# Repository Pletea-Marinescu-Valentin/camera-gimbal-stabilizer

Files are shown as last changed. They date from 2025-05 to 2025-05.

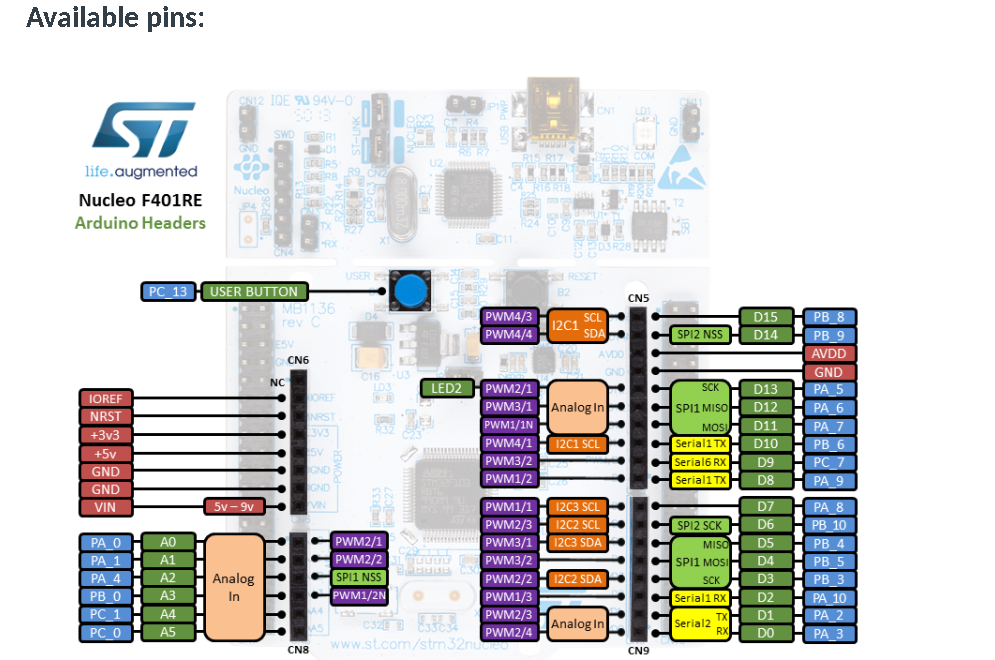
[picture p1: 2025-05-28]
Hardware/stm32-schematics.png

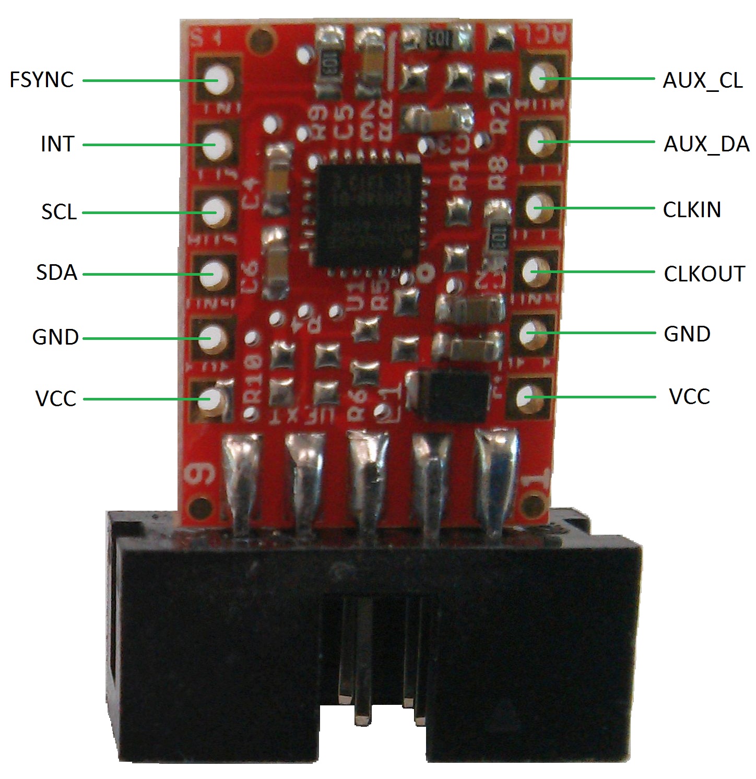
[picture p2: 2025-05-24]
Hardware/named_pins_6050.jpg

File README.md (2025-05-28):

# Camera Gimbal Stabilizer

A two-axis camera stabilization system based on STM32 microcontroller and servo motors.

## Overview

This project implements a two-axis camera gimbal stabilizer using an STM32F401RE microcontroller, MPU6050 inertial sensor, and TowerPro MG996R servo motors with DC-DC power management. The system provides camera stabilization for smooth footage during movement.

### Features

- Two-axis stabilization (pitch and roll)
- Kalman filter-based sensor fusion
- Real-time parameter adjustment via UART
- 3D printed components for mechanical assembly
- Modular design for future expansion
- Support for lightweight cameras and mobile devices
- High-precision servo control with PWM

## Bill of Materials (BOM)

| Component | Quantity | Supplier | Price/Unit | Link | Datasheet |
|---|---|---|---|---|---|
| NUCLEO-F401RE Development Board | 1 | Mouser Electronics | €13.13 | [Mouser](https://ro.mouser.com/ProductDetail/STMicroelectronics/NUCLEO-F401RE?qs=fK8dlpkaUMvGeToFJ6rzdA%3D%3D) | [STM32F401RE Datasheet](https://www.st.com/resource/en/data_brief/nucleo-c031c6.pdf) |
| MPU6050 Gyroscope/Accelerometer Module | 1 | Mouser Electronics | €8.55 | [Mouser](https://ro.mouser.com/ProductDetail/Olimex-Ltd/MOD-MPU6050?qs=SUpef6bDnvVsH%252Bq1tWOBKA%3D%3D) | [MPU6050 Datasheet](https://ro.mouser.com/datasheet/2/306/RM-MPU-60xxA_rev_4-736751.pdf) |
| TowerPro MG996R Servo Motor | 2 | TowerPro | RON 80 | [TowerPro](https://towerpro.com.tw/product/mg996r/) | [MG996R Specifications](https://towerpro.com.tw/product/mg996r/) |
| Module DC-DC Step Down LM2596S | 2 | Optimus Digital | 12.99 RON | [Optimus](https://www.optimusdigital.ro/en/adjustable-step-down-power-supplies/1109-lm2596-dc-dc-step-down-module-5a.html) | [Module Specifications](https://www.optimusdigital.ro/en/adjustable-step-down-power-supplies/1109-lm2596-dc-dc-step-down-module-5a.html) |
| Mini Breadboard | 2 | Mouser Electronics | €2.60 | [Mouser](https://ro.mouser.com/ProductDetail/OSEPP-Electronics/LS-00047?qs=w%2Fv1CP2dgqofvkXBf4F3MQ%3D%3D) | [LS-00047 Datasheet](https://www.osepp.com/accessories/components/162-ls-00047-solder-able-breadboard-mini) |
| Resistors Kit | 1 | Mouser Electronics | €10.84 | [Mouser](https://ro.mouser.com/ProductDetail/SparkFun/COM-10969?qs=WyAARYrbSnYDX0pYE0qQCg%3D%3D) | N/A |
| Plusivo Kit | 1 | Optimus Digital | RON 40 | [Optimus](https://www.optimusdigital.ro/en/kits/12026-plusivo-electronics-starter-kit-0721248990075.html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) | N/A |

## Hardware

### Components

- STM32F401RE Nucleo board
- MPU6050 accelerometer and gyroscope module
- 2× TowerPro MG996R servo motors (high-torque metal gear)
- 2× LM2596S DC-DC step-down modules
- 3D printed mechanical structure
- 12V power supply for servo motors
- USB power for STM32 development board
- Breadboard, connection wires
- Plusivo Kit (sensors, jumpers, accessories)

### Servo Motor Specifications

The TowerPro MG996R servos provide:
- **Operating voltage**: 4.8V - 7.2V (optimized at 6V)
- **Torque**: 9.4 kg⋅cm (4.8V), 11 kg⋅cm (6V)
- **Speed**: 0.20 sec/60° (4.8V), 0.17 sec/60° (6V)
- **Control signal**: PWM (50Hz, 1-2ms pulse width)
- **Weight**: 55g each
- **Metal gear construction** for durability and precision

### Power Management

The LM2596S DC-DC modules provide:
- **Input voltage**: 7V - 35V (12V nominal)
- **Output voltage**: Adjustable 1.25V - 30V (set to 6V)
- **Output current**: Up to 2A continuous
- **Efficiency**: ~85%
- **Protection**: Over-current and thermal protection

### Connections

#### MPU6050 to STM32
- SDA → PB9 (I2C1_SDA)
- SCL → PB8 (I2C1_SCL)
- VCC → 3.3V
- GND → GND

#### UART for debugging:
- TX → PA2 (USART2_TX)
- RX → PA3 (USART2_RX)

#### STM32 to Servo Motors
- PWM1 → PA6 (TIM3_CH1) - X-axis Servo
- PWM2 → PA7 (TIM3_CH2) - Y-axis Servo

#### Power Distribution
- **STM32**: 5V via USB connection
- **MPU6050**: 3.3V from STM32 regulator
- **Servo Motors**: 6V from LM2596S modules
- **DC-DC Input**: 12V external power supply

## Software

The firmware is developed using STM32CubeIDE and leverages the following technologies:

### Core Technologies
- **STM32 HAL** for hardware abstraction
- **I2C communication** for MPU6050 sensor
- **PWM generation** for servo motor control (50Hz, 1-2ms pulse width)
- **Kalman filter** for optimal sensor fusion
- **UART** for debugging and parameter adjustment

### Key Algorithms
- **Sensor Processing**: Raw data acquisition and calibration
- **Kalman Filter**: Advanced sensor fusion for stable angle estimation
- **Servo Control**: Precise PWM-based positioning
- **Real-time Processing**: 100Hz update rate

### Implementation Features
- Custom MPU6050 driver optimized for gimbal applications
- Kalman filter with gyroscope bias estimation
- Servo control with safety limits and smooth movement
- Memory management with custom allocation
- Interrupt-based processing for consistent timing

## Mathematical Model

### Kalman Filter Implementation

The system uses a 2-state Kalman filter for optimal sensor fusion:

**State Vector:**
```
x_k = [θ_k, b_k]ᵀ
```
Where:
- θ_k = Angle estimate at time k
- b_k = Gyroscope bias estimate at time k

**Prediction Step:**
```
θ_{k|k-1} = θ_{k-1|k-1} + (ω_k - b_{k-1|k-1}) × Δt
b_{k|k-1} = b_{k-1|k-1}
```

**Update Step:**
```
θ_{k|k} = θ_{k|k-1} + K_0 × (θ_accel - θ_{k|k-1})
b_{k|k} = b_{k|k-1} + K_1 × (θ_accel - θ_{k|k-1})
```

**Tuning Parameters:**
- Q_angle = 0.001 (process noise for angle)
- Q_bias = 0.003 (process noise for bias)
- R_measure = 0.03 (measurement noise)

## Results

- **Accurate orientation estimation** with significantly reduced noise
- **Stable angle measurement** even under motion or vibration
- **Real-time data reporting** through UART interface
- **Sampling rate** of approximately 100Hz
- **Smooth servo control** with precise positioning
- **Effective power management** through DC-DC conversion

## Future Improvements

- Add a third axis (yaw) for complete 3-axis stabilization
- Implement object tracking capabilities using computer vision
- Integrate wireless control system (Bluetooth/WiFi)
- Add camera trigger synchronization
- Implement auto-calibration routines
- Add mobile app for remote control and parameter adjustment

## Directory Structure

```
├── Core/
│   ├── Src/           # Source code files
│   └── Inc/           # Header files
├── Hardware/          # Electrical schematics and PCB designs
├── Models/            # 3D models for printed components
├── Images/            # Project photos and diagrams
├── Documentation/     # Detailed project documentation
└── Tests/             # Unit tests and validation data
```

## Key Files

- **main.c** - Main application logic and system initialization
- **mpu6050.c/h** - MPU6050 sensor driver and communication
- **kalman.c/h** - Kalman filter implementation
- **servo.c/h** - Servo motor control and PWM management
- **stm32f4xx_hal_msp.c** - Hardware abstraction layer configuration

## Performance Characteristics

### Power Consumption
- **Control circuits**: ~50mA at 3.3V/5V
- **Servo motors**: 10mA idle, up to 1.5A per servo under load
- **Total system**: ~3.5A peak at 12V, ~0.1A idle

### Mechanical Specifications
- **Payload capacity**: Up to 300g (lightweight cameras/phones)
- **Stabilization range**: ±45° on both axes
- **Response time**: <50ms for correction
- **Positioning accuracy**: ±0.5° in static conditions

### Communication Specifications
- **I2C frequency**: 400kHz for sensor communication
- **PWM frequency**: 50Hz for servo control
- **UART baud rate**: 115200 for debugging
- **Update rate**: 100Hz for real-time performance

## Calibration Process

1. **Gyroscope Calibration**: Automatic bias calculation during startup
2. **Accelerometer Calibration**: Six-position calibration procedure
3. **Servo Calibration**: Center position and range adjustment
4. **Filter Tuning**: Parameter optimization for specific applications

## Usage Instructions

1. **Power Connection**: Connect 12V supply to DC-DC modules
2. **USB Connection**: Connect STM32 to PC for programming and debugging
3. **Sensor Mounting**: Ensure MPU6050 is rigidly mounted to camera platform
4. **Calibration**: Follow calibration procedure for optimal performance
5. **Operation**: System automatically stabilizes once initialized

## Troubleshooting

### Common Issues
- **Servo jitter**: Check power supply stability and PWM signal quality
- **Drift**: Recalibrate gyroscope bias or adjust Kalman filter parameters
- **Poor response**: Verify mechanical connections and servo mounting
- **Communication errors**: Check I2C connections and pull-up resistors

## Resources

### Hardware Resources
- [MPU6050 User Guide](https://www.invensense.com/products/motion-tracking/6-axis/mpu-6050/)
- [NUCLEO-F401RE Documentation](https://www.st.com/en/evaluation-tools/nucleo-f401re.html)
- [TowerPro MG996R Specifications](https://towerpro.com.tw/product/mg996r/)
- [LM2596S DC-DC Module](https://www.optimusdigital.ro/en/adjustable-step-down-power-supplies/1109-lm2596-dc-dc-step-down-module-5a.html)

### Software Resources
- [STM32CubeMX](https://www.st.com/en/development-tools/stm32cubemx.html)
- [STM32CubeIDE](https://www.st.com/en/development-tools/stm32cubeide.html)
- [Kalman Filter Theory](https://github.com/TKJElectronics/KalmanFilter)
- [Servo Control Principles](https://en.wikipedia.org/wiki/Servo_control)

### Academic References
- Kalman, R.E. (1960). "A New Approach to Linear Filtering and Prediction Problems"
- Chui, C.K., Chen, G. (2017). "Kalman Filtering: With Real-Time Applications"
- Crisnapati, P.N., et al. (2023). "Enhancing Gimbal Stabilization Using DMP and Kalman Filter"

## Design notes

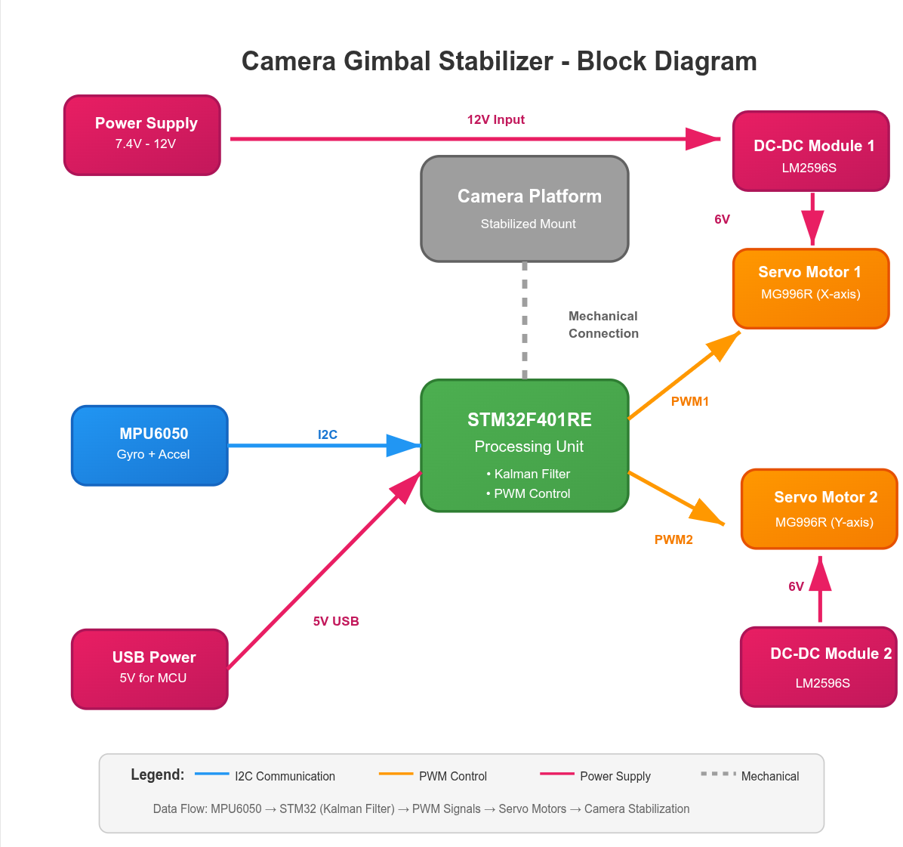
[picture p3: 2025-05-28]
Hardware/block-diagram.png

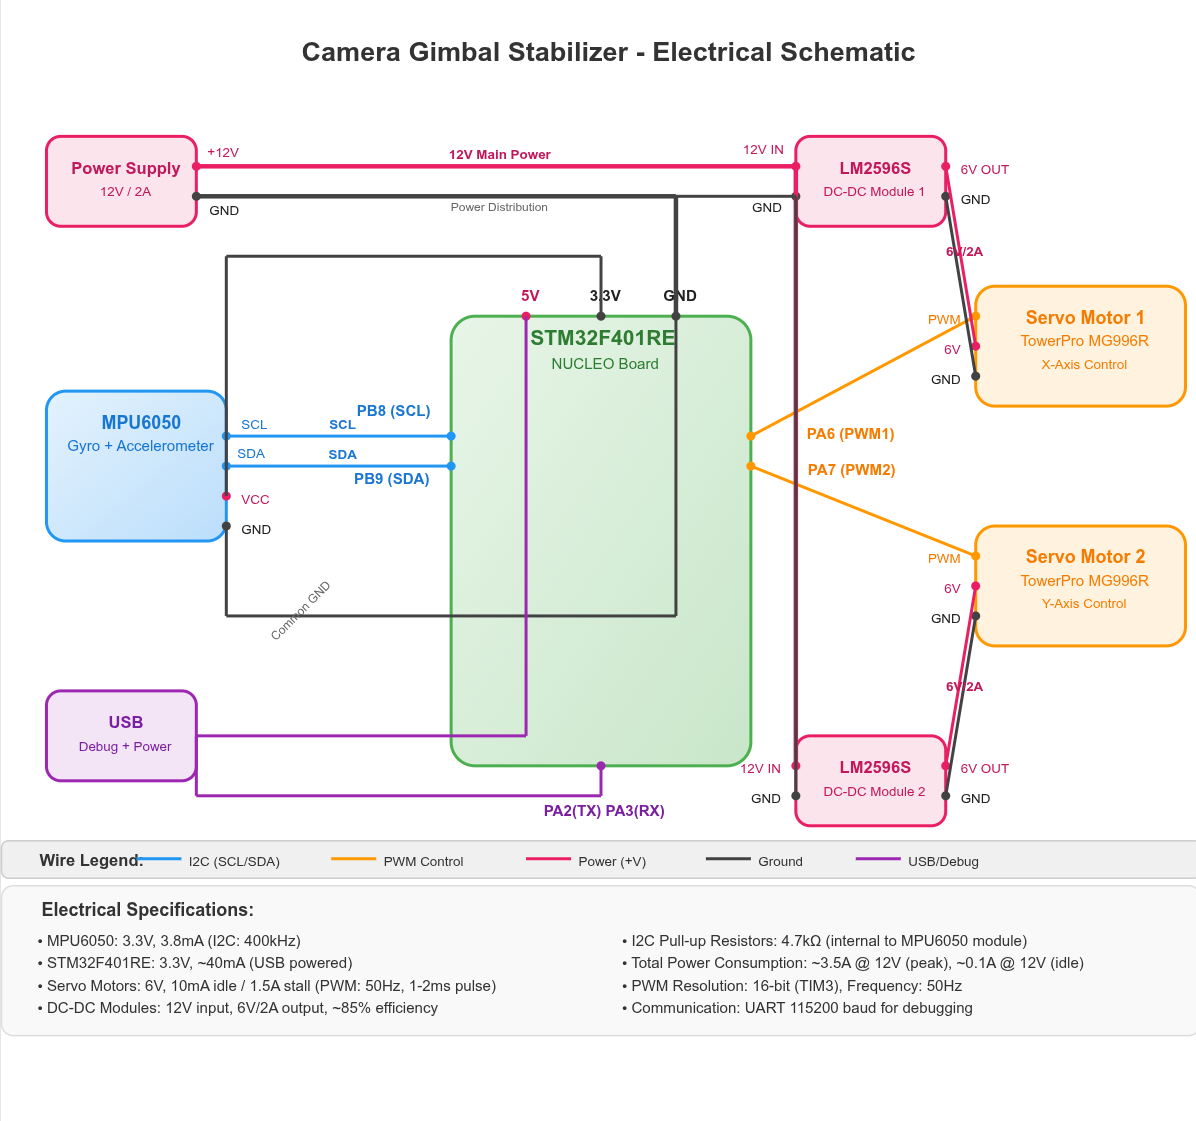
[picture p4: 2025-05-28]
Hardware/electrical-diagram.png

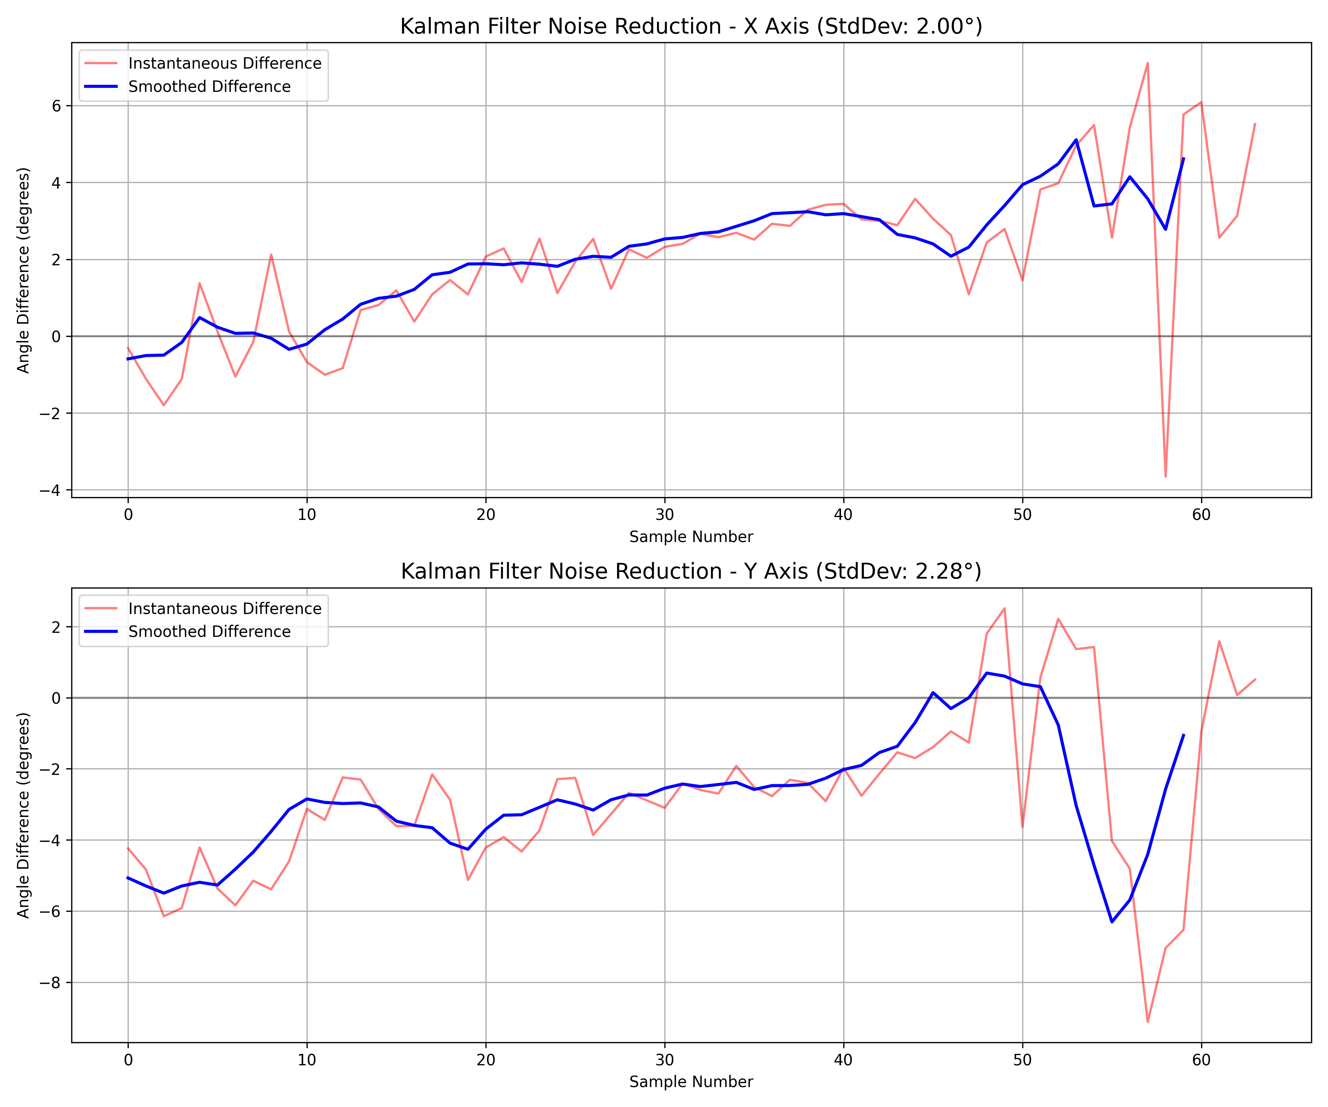
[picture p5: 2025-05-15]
Images/kalman_filter_stability.png

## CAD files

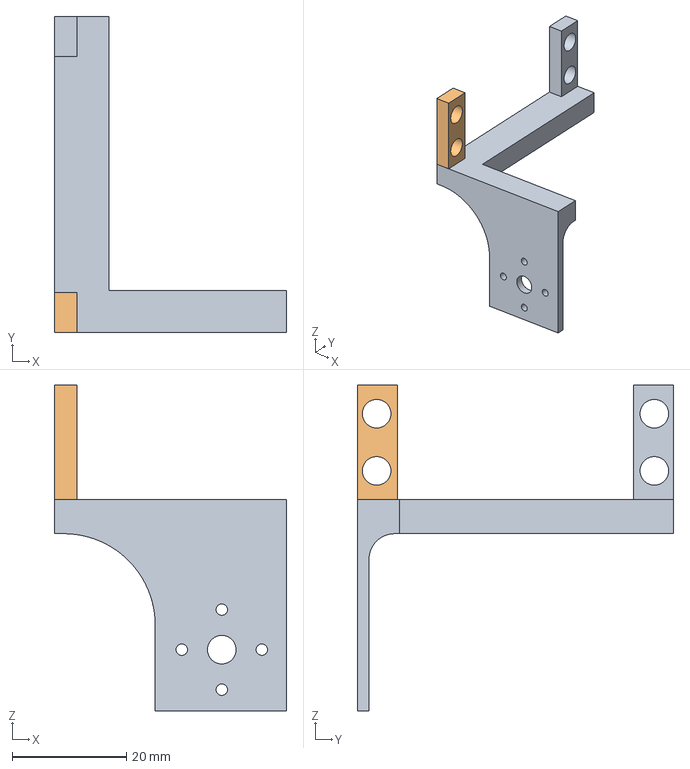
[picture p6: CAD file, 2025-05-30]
Models/SuportX.3mf
40.7 x 55.3 x 57.0 mm

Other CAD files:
Models/Base.f3d
Models/SuportY.f3d

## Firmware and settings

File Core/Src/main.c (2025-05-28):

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
/* Includes ------------------------------------------------------------------*/
#include "main.h"
#include <stdio.h>
#include <math.h>
#include "kalman.h"
#include "mpu6050.h"
#include "gimbal_control.h"
I2C_HandleTypeDef hi2c1;

TIM_HandleTypeDef htim3;

UART_HandleTypeDef huart2;

/* USER CODE BEGIN PV */
GimbalController_t gimbal;
/* USER CODE END PV */

void SystemClock_Config(void);
static void MX_GPIO_Init(void);
static void MX_I2C1_Init(void);
static void MX_TIM3_Init(void);
static void MX_USART2_UART_Init(void);
/* USER CODE BEGIN 0 */
int __io_putchar(int ch)
{
  /* Send the character to UART */
  HAL_UART_Transmit(&huart2, (uint8_t *)&ch, 1, HAL_MAX_DELAY);
  return ch;
}

Kalman_t kalmanX, kalmanY;
float angleX = 0.0f, angleY = 0.0f;
uint32_t timer = 0;
/* USER CODE END 0 */

/**
  * @brief  The application entry point.
  * @retval int
  */
int main(void)
{

  /* MCU Configuration--------------------------------------------------------*/

  /* Reset of all peripherals, Initializes the Flash interface and the Systick. */
  HAL_Init();

  /* Configure the system clock */
  SystemClock_Config();

  /* Initialize all configured peripherals */
  MX_GPIO_Init();
  MX_I2C1_Init();
  MX_TIM3_Init();
  MX_USART2_UART_Init();
  /* USER CODE BEGIN 2 */
  printf("Checking MPU6050 connection...\n");

  // Initialize MPU6050
   if (MPU6050_Init(&hi2c1) != HAL_OK) {
     printf("MPU6050 initialization failed!\r\n");
     Error_Handler();
   }

   // Check if MPU6050 is connected
   if (MPU6050_IsConnected(&hi2c1) != HAL_OK) {
     printf("MPU6050 connection failed!\r\n");
     Error_Handler();
   }

  printf("MPU6050 initialized successfully!\r\n");

  // Initialize Kalman filters
  Kalman_Init(&kalmanX);
  Kalman_Init(&kalmanY);

  printf("Initializing Gimbal...\n");

  // Initialize gimbal control (servo-based system)
  if (Gimbal_Init(&gimbal, &htim3, &hi2c1) != HAL_OK) {
      printf("Error initializing gimbal!\r\n");
      Error_Handler();
  }

  printf("Gimbal initialized successfully!\r\n");

  // Set PID parameters for servo control
  Gimbal_SetPIDGains(&gimbal, 1.8f, 0.08f, 0.03f);

  // Set initial target (center position)
  Gimbal_SetTarget(&gimbal, 0.0f, 0.0f);

  // Get initial accelerometer angles to initialize Kalman filter
  int16_t accel_x, accel_y, accel_z;
  MPU6050_ReadAccel(&hi2c1, &accel_x, &accel_y, &accel_z);

  // Calculate initial angle from accelerometer (simplified for horizontal orientation)
  float accelAngleX = atan2f((float)accel_y, (float)accel_z) * 180.0f / 3.14159f;
  float accelAngleY = atan2f((float)-accel_x, sqrtf((float)(accel_y * accel_y + accel_z * accel_z))) * 180.0f / 3.14159f;

  // Set initial angles for Kalman filter
  Kalman_SetAngle(&kalmanX, accelAngleX);
  Kalman_SetAngle(&kalmanY, accelAngleY);

  timer = HAL_GetTick();

  printf("Starting main control loop...\r\n");

  /* USER CODE END 2 */

  /* Infinite loop */
  /* USER CODE BEGIN WHILE */
  while (1) {
	  // Update gimbal control system
	  if (Gimbal_Update(&gimbal) != HAL_OK) {
		  printf("Error updating gimbal!\r\n");
	  }

	  // Read sensor data for monitoring
	  int16_t accel_x, accel_y, accel_z;
      int16_t gyro_x, gyro_y, gyro_z;
      float temp;

      // Calculate dt (in seconds)
      uint32_t now = HAL_GetTick();
      float dt = (float)(now - timer) / 1000.0f;
      timer = now;

      // Read raw sensor data
      MPU6050_ReadAccel(&hi2c1, &accel_x, &accel_y, &accel_z);
      MPU6050_ReadGyro(&hi2c1, &gyro_x, &gyro_y, &gyro_z);
      MPU6050_ReadTemp(&hi2c1, &temp);

      // Convert gyro values to degrees/sec
      float gyroX = (float)gyro_x / 131.0f;  // Divide by sensitivity scale factor
      float gyroY = (float)gyro_y / 131.0f;

      // Calculate angles from accelerometer
      float accelAngleX = atan2f((float)accel_y, (float)accel_z) * 180.0f / 3.14159f;
      float accelAngleY = atan2f((float)-accel_x, sqrtf((float)(accel_y * accel_y + accel_z * accel_z))) * 180.0f / 3.14159f;

      // Apply Kalman filter
      angleX = Kalman_GetAngle(&kalmanX, accelAngleX, gyroX, dt);
      angleY = Kalman_GetAngle(&kalmanY, accelAngleY, gyroY, dt);

      // Debug output every 100 cycles (~1Hz)
	  static int debug_counter = 0;
	  if (++debug_counter >= 100) {
		  printf("Pitch: %.2f -> %.2f | Roll: %.2f -> %.2f\r\n",
				 gimbal.current_pitch, gimbal.target_pitch,
				 gimbal.current_roll, gimbal.target_roll);
		  debug_counter = 0;
	  }

      // Optional: Print raw and filtered values for debugging
	  // printf("Raw Accel X: %6d, Y: %6d, Z: %6d\r\n", accel_x, accel_y, accel_z);
	  // printf("Raw Gyro  X: %6d, Y: %6d, Z: %6d\r\n", gyro_x, gyro_y, gyro_z);
	  // printf("Filtered X: %.2f, Y: %.2f\r\n", angleX, angleY);
	  // printf("Temp: %.2f C\r\n\n", temp);

      HAL_Delay(10);  // ~100Hz update rate
    }

    /* USER CODE END WHILE */

    /* USER CODE BEGIN 3 */
  }
  /* USER CODE END 3 */

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
/* USER CODE BEGIN 4 */
int _write(int file, char *ptr, int len)
{
  (void)file;
  int DataIdx;

  for (DataIdx = 0; DataIdx < len; DataIdx++)
  {
    ITM_SendChar(*ptr++);
  }
  return len;
}

/* USER CODE END 4 */
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


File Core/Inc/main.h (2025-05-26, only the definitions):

#define B1_Pin GPIO_PIN_13
#define B1_GPIO_Port GPIOC
#define USART_RX_Pin GPIO_PIN_3
#define USART_RX_GPIO_Port GPIOA
#define LD2_Pin GPIO_PIN_5
#define LD2_GPIO_Port GPIOA
#define IN4_Pin GPIO_PIN_10
#define IN4_GPIO_Port GPIOB
#define TMS_Pin GPIO_PIN_13
#define TMS_GPIO_Port GPIOA
#define TCK_Pin GPIO_PIN_14
#define TCK_GPIO_Port GPIOA
#define SWO_Pin GPIO_PIN_3
#define SWO_GPIO_Port GPIOB
#define IN1_Pin GPIO_PIN_4
#define IN1_GPIO_Port GPIOB
#define IN2_Pin GPIO_PIN_5
#define IN2_GPIO_Port GPIOB
#define IN3_Pin GPIO_PIN_6
#define IN3_GPIO_Port GPIOB

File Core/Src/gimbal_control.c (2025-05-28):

#include "gimbal_control.h"
#include <math.h>

// Configuration constants
#define SERVO_MIN_PULSE_US    500  // Minimum servo pulse width
#define SERVO_MAX_PULSE_US    2500  // Maximum servo pulse width
#define SERVO_CENTER_PULSE_US 1500  // Center servo pulse width
#define SERVO_PWM_PERIOD_US   20000 // PWM period (20ms for 50Hz)

#define MAX_TILT_ANGLE        45.0f // Maximum tilt angle in degrees

// Private functions
static void Gimbal_ControlServo(GimbalController_t *gimbal, uint8_t channel, float angle);
static float Gimbal_PIDControl(GimbalController_t *gimbal, float setpoint, float current,
                              float dt, uint8_t axis);

HAL_StatusTypeDef Gimbal_Init(GimbalController_t *gimbal,
                             TIM_HandleTypeDef *htim_servo,
                             I2C_HandleTypeDef *hi2c)
{
    // Initialize structure
    gimbal->htim_servo = htim_servo;
    gimbal->hi2c = hi2c;

    // Initialize Kalman filters
    Kalman_Init(&gimbal->kalman_pitch);
    Kalman_Init(&gimbal->kalman_roll);

    // Default PID settings
    gimbal->kp = 2.0f;
    gimbal->ki = 0.1f;
    gimbal->kd = 0.05f;
    gimbal->integral_pitch = 0.0f;
    gimbal->integral_roll = 0.0f;
    gimbal->last_error_pitch = 0.0f;
    gimbal->last_error_roll = 0.0f;

    // Default targets (center position)
    gimbal->target_pitch = 0.0f;
    gimbal->target_roll = 0.0f;

    // Servo settings
    gimbal->servo_center_us = SERVO_CENTER_PULSE_US;
    gimbal->servo_range_us = (SERVO_MAX_PULSE_US - SERVO_MIN_PULSE_US) / 2;
    gimbal->max_angle = MAX_TILT_ANGLE;

    // Initialize MPU6050
    if (MPU6050_Init(gimbal->hi2c) != HAL_OK) {
        return HAL_ERROR;
    }

    if (MPU6050_IsConnected(gimbal->hi2c) != HAL_OK) {
        return HAL_ERROR;
    }

    // Start PWM for servos
    if (HAL_TIM_PWM_Start(gimbal->htim_servo, TIM_CHANNEL_1) != HAL_OK ||
        HAL_TIM_PWM_Start(gimbal->htim_servo, TIM_CHANNEL_2) != HAL_OK) {
        return HAL_ERROR;
    }

    // Position servos to center
    Gimbal_ControlServo(gimbal, 1, 0.0f); // Pitch servo
    Gimbal_ControlServo(gimbal, 2, 0.0f); // Roll servo

    // Read initial value for Kalman filter
    int16_t accel_x, accel_y, accel_z;
    if (MPU6050_ReadAccel(gimbal->hi2c, &accel_x, &accel_y, &accel_z) == HAL_OK) {
        float initial_pitch = atan2f((float)accel_y, (float)accel_z) * 180.0f / M_PI;
        float initial_roll = atan2f((float)-accel_x,
                                   sqrtf((float)(accel_y * accel_y + accel_z * accel_z))) * 180.0f / M_PI;

        Kalman_SetAngle(&gimbal->kalman_pitch, initial_pitch);
        Kalman_SetAngle(&gimbal->kalman_roll, initial_roll);
    }

    gimbal->last_update_time = HAL_GetTick();

    return HAL_OK;
}

HAL_StatusTypeDef Gimbal_Update(GimbalController_t *gimbal)
{
    // Calculate dt
    uint32_t current_time = HAL_GetTick();
    float dt = (float)(current_time - gimbal->last_update_time) / 1000.0f;
    gimbal->last_update_time = current_time;

    // Read sensor data
    int16_t accel_x, accel_y, accel_z;
    int16_t gyro_x, gyro_y, gyro_z;

    if (MPU6050_ReadAccel(gimbal->hi2c, &accel_x, &accel_y, &accel_z) != HAL_OK ||
        MPU6050_ReadGyro(gimbal->hi2c, &gyro_x, &gyro_y, &gyro_z) != HAL_OK) {
        return HAL_ERROR;
    }

    // Convert gyroscope to degrees/sec
    float gyro_pitch = (float)gyro_x / 131.0f;
    float gyro_roll = (float)gyro_y / 131.0f;

    // Calculate angles from accelerometer
    float accel_pitch = atan2f((float)accel_y, (float)accel_z) * 180.0f / M_PI;
    float accel_roll = atan2f((float)-accel_x,
                             sqrtf((float)(accel_y * accel_y + accel_z * accel_z))) * 180.0f / M_PI;

    // Apply Kalman filter
    gimbal->current_pitch = Kalman_GetAngle(&gimbal->kalman_pitch, accel_pitch, gyro_pitch, dt);
    gimbal->current_roll = Kalman_GetAngle(&gimbal->kalman_roll, accel_roll, gyro_roll, dt);

    // Calculate PID output for servos
    float servo_pitch_output = Gimbal_PIDControl(gimbal, gimbal->target_pitch,
                                                gimbal->current_pitch, dt, 0);
    float servo_roll_output = Gimbal_PIDControl(gimbal, gimbal->target_roll,
                                               gimbal->current_roll, dt, 1);

    // Limit servo angles
    if (servo_pitch_output > gimbal->max_angle) servo_pitch_output = gimbal->max_angle;
    if (servo_pitch_output < -gimbal->max_angle) servo_pitch_output = -gimbal->max_angle;
    if (servo_roll_output > gimbal->max_angle) servo_roll_output = gimbal->max_angle;
    if (servo_roll_output < -gimbal->max_angle) servo_roll_output = -gimbal->max_angle;

    // Control servos for stabilization
    Gimbal_ControlServo(gimbal, 1, servo_pitch_output); // Pitch axis
    Gimbal_ControlServo(gimbal, 2, servo_roll_output);  // Roll axis

    return HAL_OK;
}

static void Gimbal_ControlServo(GimbalController_t *gimbal, uint8_t channel, float angle)
{
    // Convert angle to pulse time (microseconds)
    float pulse_us = gimbal->servo_center_us + (angle / gimbal->max_angle) * gimbal->servo_range_us;

    // Limit values
    if (pulse_us < SERVO_MIN_PULSE_US) pulse_us = SERVO_MIN_PULSE_US;
    if (pulse_us > SERVO_MAX_PULSE_US) pulse_us = SERVO_MAX_PULSE_US;

    // Convert to PWM value (assuming TIM3 configured for 20ms period)
    // ARR should be set to achieve 20ms period at current clock frequency
    uint32_t timer_period = __HAL_TIM_GET_AUTORELOAD(gimbal->htim_servo) + 1;
    uint32_t pwm_value = (uint32_t)((pulse_us * timer_period) / SERVO_PWM_PERIOD_US);

    // Set PWM
    if (channel == 1) {
        __HAL_TIM_SET_COMPARE(gimbal->htim_servo, TIM_CHANNEL_1, pwm_value);
    } else if (channel == 2) {
        __HAL_TIM_SET_COMPARE(gimbal->htim_servo, TIM_CHANNEL_2, pwm_value);
    }
}

static float Gimbal_PIDControl(GimbalController_t *gimbal, float setpoint, float current,
                              float dt, uint8_t axis)
{
    float error = setpoint - current;

    float *integral = (axis == 0) ? &gimbal->integral_pitch : &gimbal->integral_roll;
    float *last_error = (axis == 0) ? &gimbal->last_error_pitch : &gimbal->last_error_roll;

    // Integral term with anti-windup
    *integral += error * dt;
    if (*integral > 10.0f) *integral = 10.0f;
    if (*integral < -10.0f) *integral = -10.0f;

    // Derivative term
    float derivative = (error - *last_error) / dt;

    // Calculate PID output
    float output = gimbal->kp * error + gimbal->ki * (*integral) + gimbal->kd * derivative;

    *last_error = error;

    return output;
}

void Gimbal_SetTarget(GimbalController_t *gimbal, float pitch, float roll)
{
    gimbal->target_pitch = pitch;
    gimbal->target_roll = roll;
}

void Gimbal_SetPIDGains(GimbalController_t *gimbal, float kp, float ki, float kd)
{
    gimbal->kp = kp;
    gimbal->ki = ki;
    gimbal->kd = kd;
}
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

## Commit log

2025-05-15 Initial commit: setup configuration in STM32CubeIDE + .ioc file for I2C
2025-05-15 fix: using SWV and add function for making printf useable in console
    [main.c]
2025-05-15 Add header for declaring functions and registers for implementing the connectivity with mpu6050 sensor
2025-05-15 Add the implementations for checking connectivity and reading x,y and z values, from sensor
2025-05-15 Add Kalman Filter implementation to this system: initializing the filter and check for intermediate states
2025-05-15 Update Main file, testing the Kalman filter
2025-05-15 add implementation in python witch use .txt file like a dataset for checking imperfections in Kalman Filter
2025-05-15 Add BOM
2025-05-16 added electrical schematics diagram
2025-05-24 Upload MPU6050 Schematic
2025-05-24 Upload Motor Schematics
2025-05-24 PWM Configuration for Brushless Motors
2025-05-24 Fix: setup problems about SWM ITM Data Console
    [camera-gimbal-stabilizer.ioc, main.c, main.h]
2025-05-24 Implemented the logic for using the motors
2025-05-26 feat: implement working implementation of 2 servo motors, applying Kalman filter on them
2025-05-28 feat: strucutre based on new specs -> servo and DC-DC module
2025-05-28 Upload stm32NuceloF401RE diagram about pin config.
2025-05-28 Upload supports for servo motors on X and Y axis, and base platform
    [Base.f3d, SuportX.f3d, SuportY.f3d]
2025-05-28 feat: PWM config for Servo Motors
2025-05-28 feat: increase speed for motors
2025-05-30 Update X Suport
    [SuportX.3mf]

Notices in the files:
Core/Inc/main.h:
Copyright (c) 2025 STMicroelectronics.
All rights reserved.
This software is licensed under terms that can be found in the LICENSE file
